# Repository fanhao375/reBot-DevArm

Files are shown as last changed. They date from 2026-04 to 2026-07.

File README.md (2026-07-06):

# 🦾 reBot-DevArm: Open Source Robotic Arm for All Developers

<p align="center">
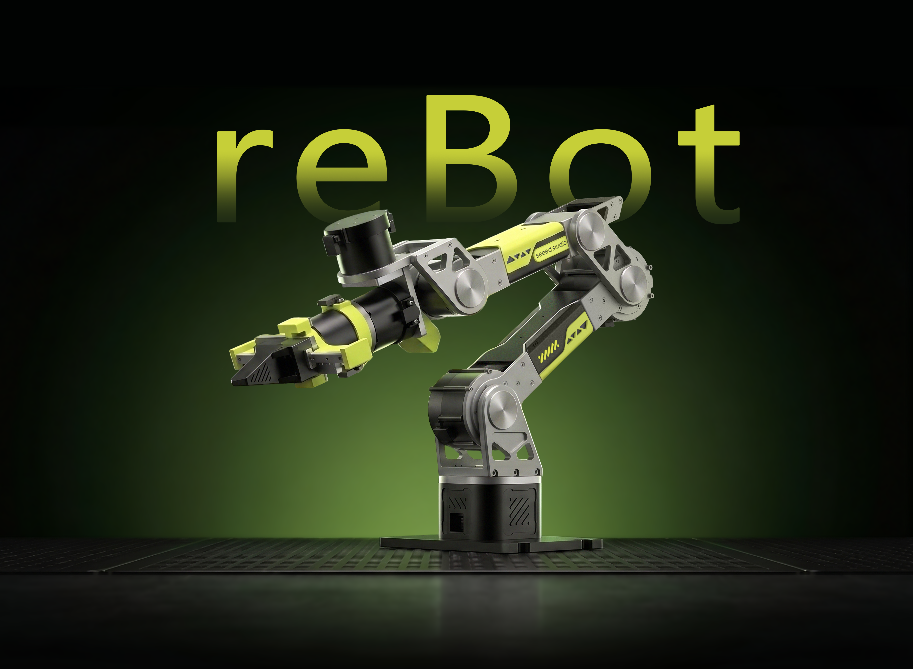
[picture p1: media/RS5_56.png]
reBot-DevArm Banner
  
</p>

<p align="center">
    <a href="https://certification.oshwa.org/cn000024.html">
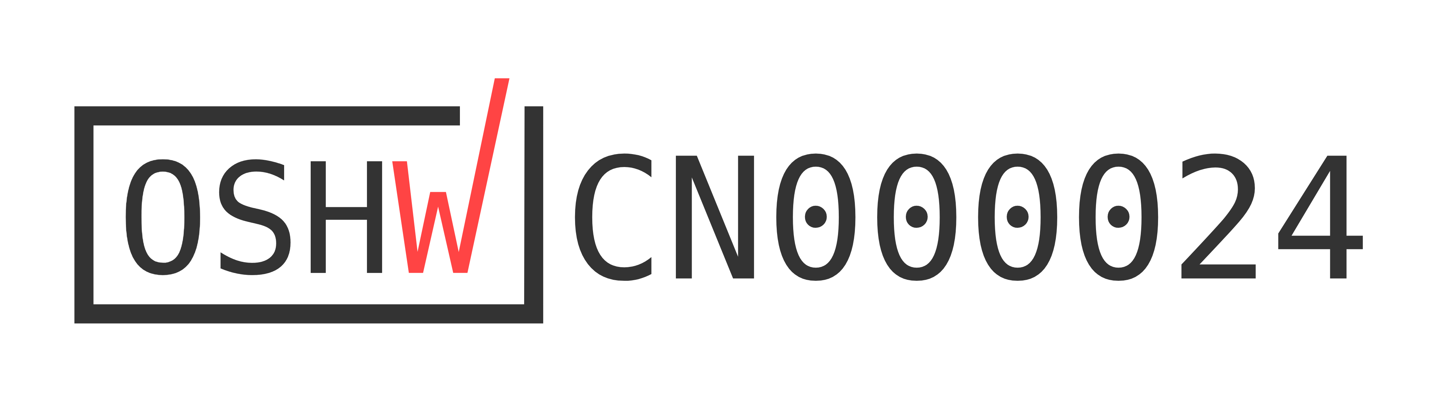
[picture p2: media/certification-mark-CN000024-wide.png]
  
</a>
</p>

<p align="center">
    <a href="./LICENSE">
    
    </a>
    
    </a>
    
    
    
    
</p>

<p align="center">
  <strong>🚀 100% Open Source · Embodied AI · Full Hardware + Software Stack</strong>
</p>

<p align="center">
  <strong>📦 Build your own robotic arm · 🧠 Learn robotics · 🏭 Deploy real applications</strong>
</p>

<table align="center">
  <tr>
    <td>
      <a href="https://www.youtube.com/watch?v=ONbpv3seiG8">
        
      </a>
    </td>
    <td>
      <a href="https://www.youtube.com/watch?v=ONbpv3seiG8">
        About The reBot Arm
      </a>
    </td>
  </tr>
</table>

<p align="center">
  <strong>
    <a href="./README_zh.md">简体中文</a> &nbsp;|&nbsp;
    <a href="./README.md">English</a> &nbsp;|&nbsp;
    <a href="./README_JP.md">日本語</a>&nbsp;|&nbsp;
    <a href="./README_Fr.md">français</a>&nbsp;|&nbsp;
    <a href="./README_es.md">Español</a>
  </strong>
</p>

<p align="center">
<a href="https://discord.gg/AbGuqJhDpQ">
    </a>
<a href="https://wiki.seeedstudio.com/robotics_page/">  
    </a>
</p>

## 📖 Introduction

**reBot-DevArm (reBot Arm B601 DM and reBot Arm B601 RS)** is a robotic arm project dedicated to lowering the barrier to learning Embodied AI. We focus on **"True Open Source"** — not just the code, we unreservedly open source everything:
- 🦾 **Two versions of the robotic arm**：We will provide all open-source files for two versions of the robotic arm with the same appearance: **Robostride** and **Damiao**.
- 🛠️ **Hardware Blueprints**: Source files for sheet metal parts and 3D printed parts.
- 🔩 **BOM List**: Detailed down to the specifications and purchase links for every single screw.
- 💻 **Software & Algorithms**: Python SDK, ROS1/2, Isaac Sim, LeRobot, etc.

## Get Your Own reBot Arm

- We offer five kit options  at  [Seeedstudio.com](https://www.seeedstudio.com/reBot-Arm-B601-DM-Bundle.html) :
  - **Arm Body Motor Kit**: Includes only motors and wiring harnesses for the robotic arm.
  - **Arm Body Structural Kit**: Includes only mechanical structural components.
  - **Gripper Complete Kit**: Includes motors, wiring harnesses and structural components for the gripper.
  - **Full Kit**: Includes the complete set of the robotic arm body and gripper.
  - **Pre‑assembled Robotic Arm**: Fully assembled finished robotic arm.

- The Seeedstudio kit does not include a power adapter and C-clamps as standard accessories. This arrangement takes into account that users may power the unit via batteries or mount it with a custom DIY base. You may purchase a [power supply separately](https://www.seeedstudio.com/AC-DC-Power-Adapter-IEC-60320-C14-XT30-Female-24V-4-5A-1200mm-L190-W92-5-H36mm-p-6764.html) and [Power Cord](https://www.seeedstudio.com/reServer-AC-US-p-5052.html), or refer to the Mean Well power solution shown at the bottom of our [BOM](./hardware/reBot_B601_DM/readme.md/#about-power-supply).

- You can also purchase the [Leader Arm](https://www.seeedstudio.com/Star-Arm-102-p-6765.html?qid=P2U7IG_yskyak5m_1776415593315) and [12V 10A Power Supply](https://www.seeedstudio.com/FY1209900-12V-10A-Power-Adapter-12V-10A-p-6496.html) You may also use the 12VDC power adapter of SO-ARM101 to supply power to the Leader.

-------------------
- For reBot Arm RS Version, We offer five kit options  at  [Seeedstudio.com](https://www.seeedstudio.com/reBot-Arm-B601-RS-Assembled-Kit-with-Gripper-p-6865.html) :
  - **Full Kit**: Includes the unassembled complete set of the robotic arm body and gripper.
  - **Pre‑assembled Robotic Arm**: Fully assembled finished robotic arm.

- We highly recommend using the [Meanwell 48V 12.5A](https://www.amazon.com/sspa/click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) power supply for the RS model. If you need stronger power to unlock its full performance, you may opt for a 48V 25A power adapter.
------------------

## 🗺️ Roadmap & Status

We are committed to continuously maintaining and adapting to mainstream robot development ecosystems. Below is our current adaptation progress and planned release schedule:

### reBot Arm B601 DM
| Supported Ecosystem | Status | Description / Estimated Release Date | Related Documentation |
| :--- | :---: | :--- | :--- |
| **Basic Motor Usage** | ✅ Completed | Basic motion control and API encapsulation | [Damiao Technology](https://wiki.seeedstudio.com/cn/damiao_series/) |
| **Open-Sourcing of the New STEP 3D Structural Parts and BOM** | ✅ Completed | STEP files for all parts in the new version, parts BOM, and reference prices for all machined components | [reBot Arm B601-DM BOM](./hardware/reBot_B601_DM/readme.md) |
| **Reference for Real Machine Performance Testing** | ✅ Completed | Performance Reference of Robotic Arm under Normal and Extreme Operating Conditions |[Performance Testing](./hardware/reBot_B601_DM/performance_testing/Performance_Testing.md) |
| **Assembly Video** | ✅ Completed | Ultra-detailed assembly steps and video | [Getting Started with reBot Arm B601-DM](https://wiki.seeedstudio.com/rebot_b601_dm_getting_started/) |
| **Python SDK** | ✅Continuously optimized, PRs welcome | One-stop integration of motor read/write and control for Robstride, Damiao, Mota, Gaoqing, Hexfellow and other motors. | [Getting Started with Motorbridge](https://motorbridge.seeedstudio.com) and [Web UI](https://rebot-devarm.w0x7ce.eu/)|
| **ROS2 Integration** | ✅ Completed | ROS2 integrated reBot Arm controller with support for kinematics, trajectory planning, and gravity compensation | [reBot Arm B601-DM ROS2 Integration Guide](https://wiki.seeedstudio.com/rebot_arm_b601_dm_ros2_integration/) |
| **Pinocchio Integration** |  ✅ Completed  | Adaptation to the Pinocchio framework, enabling forward/inverse kinematics and gravity compensation for the robotic arm | [Getting Started with Pinocchio for reBot Arm B601-DM](https://wiki.seeedstudio.com/rebot_arm_b601_dm_pinocchio_meshcat/) and [Github repo](https://github.com/vectorBH6/reBotArm_control_py) |
| **Isaac Sim Simulation** | 🚧 In Progress  | Import USD models and enable simulated teleoperation | [delay for add additional courses: 2026.06.20] |
| **LeRobot Integration** | ✅ Completed  | Adaptation to the Hugging Face LeRobot training framework | [Getting Started with LeRobot-based reBot Arm](https://wiki.seeedstudio.com/rebot_arm_b601_dm_lerobot/) |
| **Depth Camera Integration** | ✅ Completed  | Visual Grasping Demonstration Based on YOLO and Depth Camera | [Getting Started with Visual Grasping Demo](https://wiki.seeedstudio.com/rebot_arm_b601_dm_grasping_demo/) |
| **reSpeaker Voice Integration** | ✅ Completed  | Add reSpeaker Flex 4-mic array to build a voice-driven intelligent robot arm control system with spatial awareness | [reBot Arm B601-DM Voice Control](https://wiki.seeedstudio.com/control_rebot_arm_using_voice_with_respeaker_flex/) |
| **Gradual Updates of the Latest Algorithms** | ⏳ Planned | Mainstream algorithms will be updated progressively | Ongoing |
| **Launch of a Series of Completely Free Courses** | ⏳ Planned | Mainstream algorithms will be updated progressively | Ongoing |

#### Contributions from Developers 
| Supported Ecosystem | Authors | Description / Estimated Release Date | Related Documentation or Repository |
| :--- | :---: | :--- | :--- |
| **ROS2 (Humble), third_party integration, URDF / rebotarm_bringup** | [@danieldoradotalaveron-rb](https://github.com/danieldoradotalaveron-rb) | 1. **Passive diagnostics monitor** (`rebotarm_monitor_ros2`): `/diagnostics` overlay for `rqt_robot_monitor`, serial/CAN-aware aggregator;<br>2. **Safe park & shutdown**: Capture rest pose on connect, slow return on shutdown or `/rebotarm/park` to prevent sudden drop;<br>3. **Gravity compensation (smooth stop)**: MIT ramp-out when exiting gravity compensation to eliminate clack, jerk and instability during pos/vel handoff;<br>4. **Gamepad teleop with IK/FK and safety measures**: Gamepad control for end-effector via IK, live robot state visualization in RViz (simulation-only test);<br>5. **D405 eye-in-hand TF**: Xacro setup under `end_link` in `rebotarm_bringup` for RViz visualization & TF only (no driver/depth/intrinsics). Mount pose adjustable via launch file, bracket calibration not completed. Teleop FK/IK uses arm-only `fixend_core` URDF, full xacro for RSP/RViz. | [rebotarm_monitor_ros2](https://github.com/danieldoradotalaveron-rb/rebotarm_monitor_ros2)、[reBotArmController_ROS2](https://github.com/danieldoradotalaveron-rb/reBotArmController_ROS2) |

### reBot Arm B601 RS

| Supported Ecosystem | Status | Description / Estimated Release Date | Related Documentation |
| :--- | :---: | :--- | :--- |
| **Basic Motor Usage** | ✅ Completed | Basic motion control and API encapsulation | [Robstride](https://wiki.seeedstudio.com/cn/robstride_control/) |
| **Open-Sourcing of the New STEP 3D Structural Parts and BOM** | 🚧 In Progress | STEP files for all parts in the new version, parts BOM, and reference prices for all machined components | Expected [2026.06] |
|**Getting Started**| ✅ Completed | Quick start of B601-RS| [Getting Started with reBot Arm B601-RS](https://wiki.seeedstudio.com/rebot_b601_rs_getting_started/) |
| **Assembly Video** | 🚧 In Progress | Ultra-detailed assembly steps and video | [Expected 2026.06] |
| **ROS2 (Humble)** | ✅ Completed | ROS2 integrated reBot Arm controller with support for kinematics, trajectory planning, gravity compensation and MoveIt2 | [reBot Arm B601-DM ROS2 Integration Guide](https://wiki.seeedstudio.com/rebot_arm_b601_rs_ros2_integration/) |
| **LeRobot Integration** |✅ Completed| Adaptation to the Hugging Face LeRobot training framework | [Getting Started with LeRobot-based reBot Arm](https://wiki.seeedstudio.com/rebot_arm_b601_rs_lerobot/) |
| **Pinocchio Integration** | ✅ Completed | Adaptation to the Pinocchio framework, enabling forward/inverse kinematics and gravity compensation for the robotic arm | [Getting Started with Pinocchio for reBot Arm B601-DM](https://wiki.seeedstudio.com/rebot_arm_b601_rs_pinocchio_meshcat/) and [Github repo](https://github.com/vectorBH6/reBotArm_control_py) |
| **Depth Camera Integration** | ✅ Completed  | Visual Grasping Demonstration Based on YOLO and Depth Camera | [Getting Started with Visual Grasping Demo](https://wiki.seeedstudio.com/rebot_arm_b601_dm_grasping_demo/) |
| **Isaac Sim Simulation** | ⏳ Planned | Import USD models and enable simulated teleoperation | [Github Repo](https://github.com/Seeed-Projects/reBot-Isaacsim) |
| **Gradual Updates of the Latest Algorithms** | ⏳ Planned | Mainstream algorithms will be updated progressively | On going |
| **Launch of a Series of Completely Free Courses** | ⏳ Planned | Mainstream algorithms will be updated progressively | Ongoing |

---

## ⚙️ Hardware Specifications

reBot-DevArm is designed for desktop Embodied AI applications, balancing payload capacity with flexibility.

| Parameter | reBot Arm B601-DM | reBot Arm B601-RS|
| :--- | :--- | :--- |
| **Payload** | 1.5kg | **2.5kg** |
| **Recommended Workspace** | 70% arm reach workspace | 70% arm reach workspace |
| **Max Reach** | 767 mm | **754 mm** |
| **Weight** | **Approx. 4.5 kg** | Approx. 6.7 kg |
| **Repeatability** | < 0.2 mm | < 0.2 mm |
| **Degrees of Freedom (DOF)** | 6 DOF + 1 Gripper | 6 DOF + 1 Gripper |
| **Supported Platforms/Ecosystems** | ROS1, ROS2, LeRobot, Pinocchio, Isaac Sim, Python SDK | ROS1, ROS2, LeRobot, Pinocchio, Isaac Sim, Python SDK |
| **Supply Voltage** | DC 24V | DC 48V |

## Feedback from the community
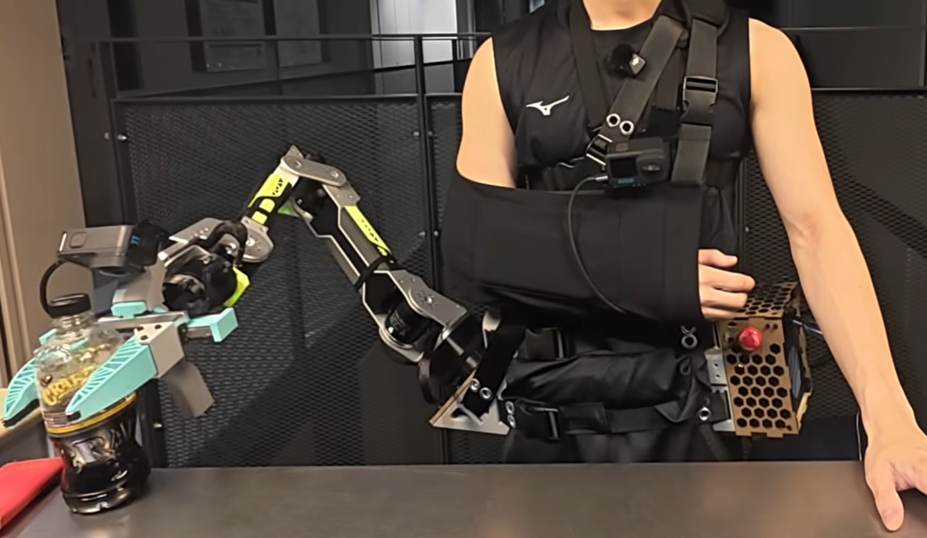
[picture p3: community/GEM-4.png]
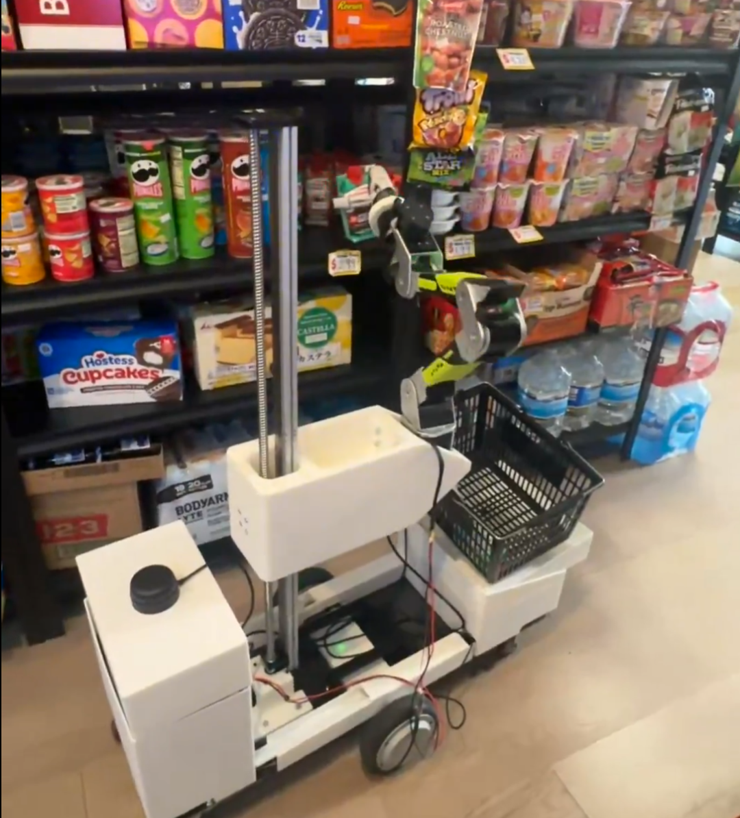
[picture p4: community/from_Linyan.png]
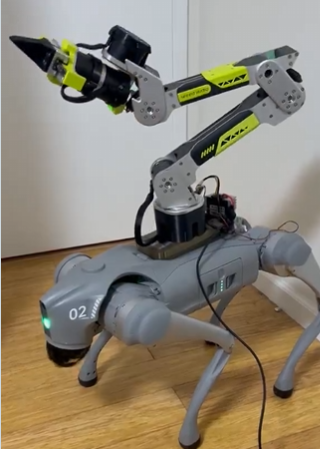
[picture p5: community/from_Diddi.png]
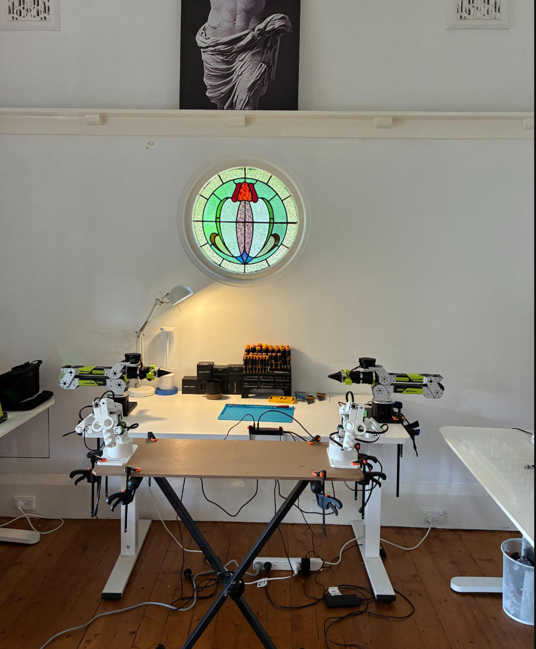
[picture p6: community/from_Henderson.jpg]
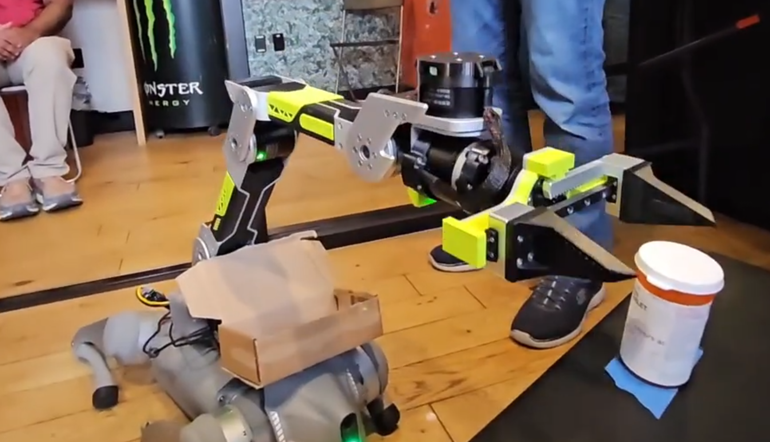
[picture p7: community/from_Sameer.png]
|  |  |  |  | |
| --- | --- | --- | --- |  --- |
| [From GEM-4: Gemma Embodied 4 Physical Assistance](https://www.kaggle.com/competitions/gemma-4-good-hackathon/writeups/new-writeup-1778618527713) | [From Linyan Fu](https://x.com/Linyan_Fu/status/2056383947341525180)  and [Apheth D Almeida](https://x.com/Apheth_DAlmeida/status/2053503164507476096)| [From Dhruv Diddi](https://x.com/DhruvDiddi/status/2046605015008383284)  | [From Ed Henderson](https://x.com/ed0henderson/status/2055076839002095743)  | From Sameer | 
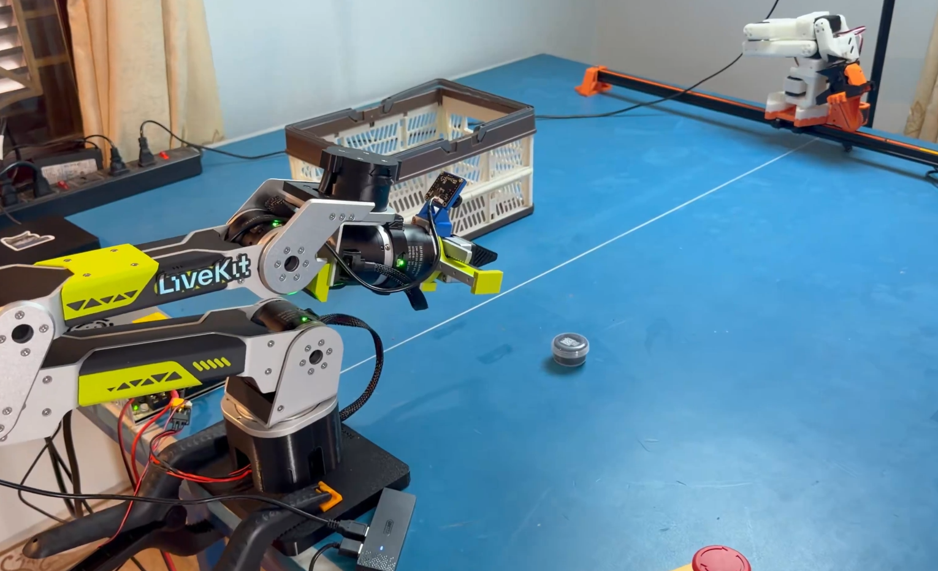
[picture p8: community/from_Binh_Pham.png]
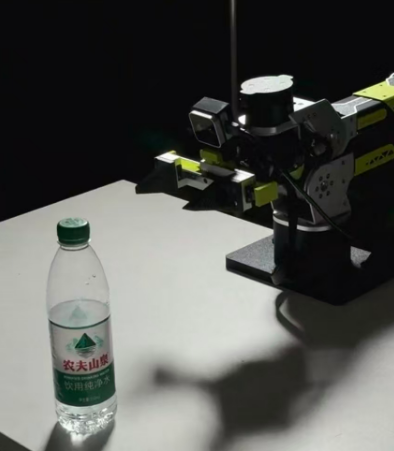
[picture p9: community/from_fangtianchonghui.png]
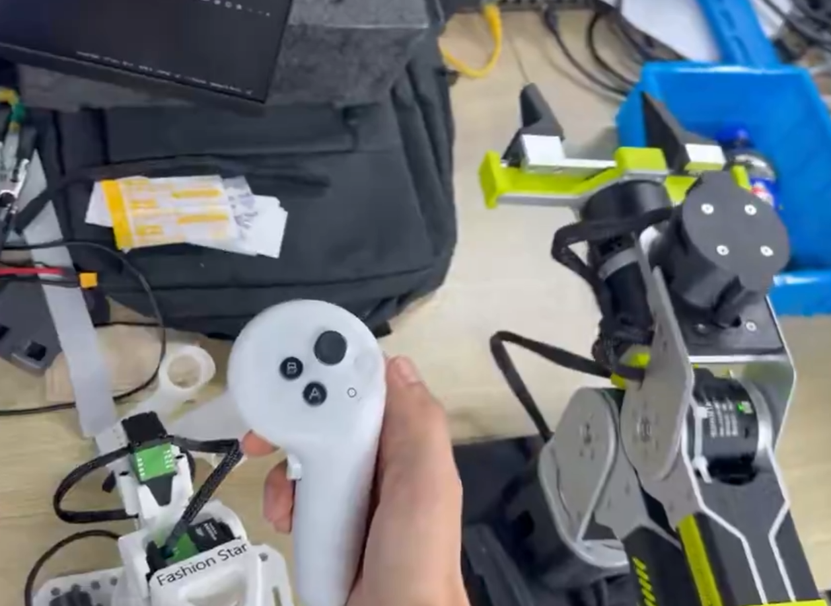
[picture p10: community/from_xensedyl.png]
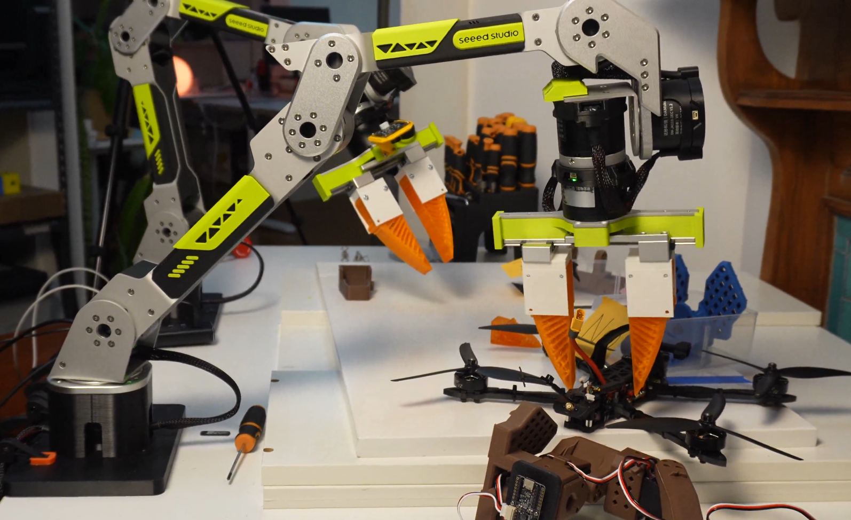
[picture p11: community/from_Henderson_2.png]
|  |  |  |  | |
| [From Binh_Pham](https://x.com/pham_blnh/status/2061994096374505710) | [From FangTianChongHui](https://www.instagram.com/reel/DY7Ny8OPjVu/?utm_source=ig_web_copy_link&igsh=NTc4MTIwNjQ2YQ==)| [Xense YaoLin Dong](https://x.com/dong1505lin)  | [From Ed Henderson](https://x.com/ed0henderson/status/2055076839002095743)  | | 

## 🧹Optional Hardware
###  Wirst Camera Mount
| 32×32 UVC  | Intel D435i | Intel D405 & Gemini 305 | Gemini 2|
| --- | --- | --- | --- |
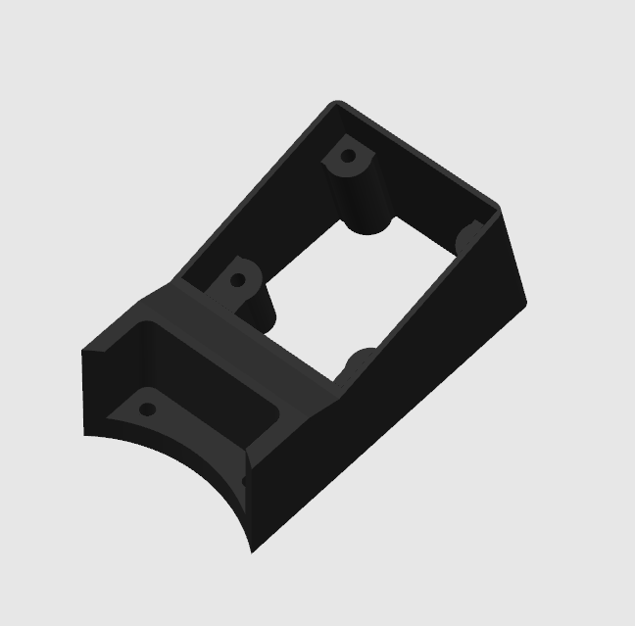
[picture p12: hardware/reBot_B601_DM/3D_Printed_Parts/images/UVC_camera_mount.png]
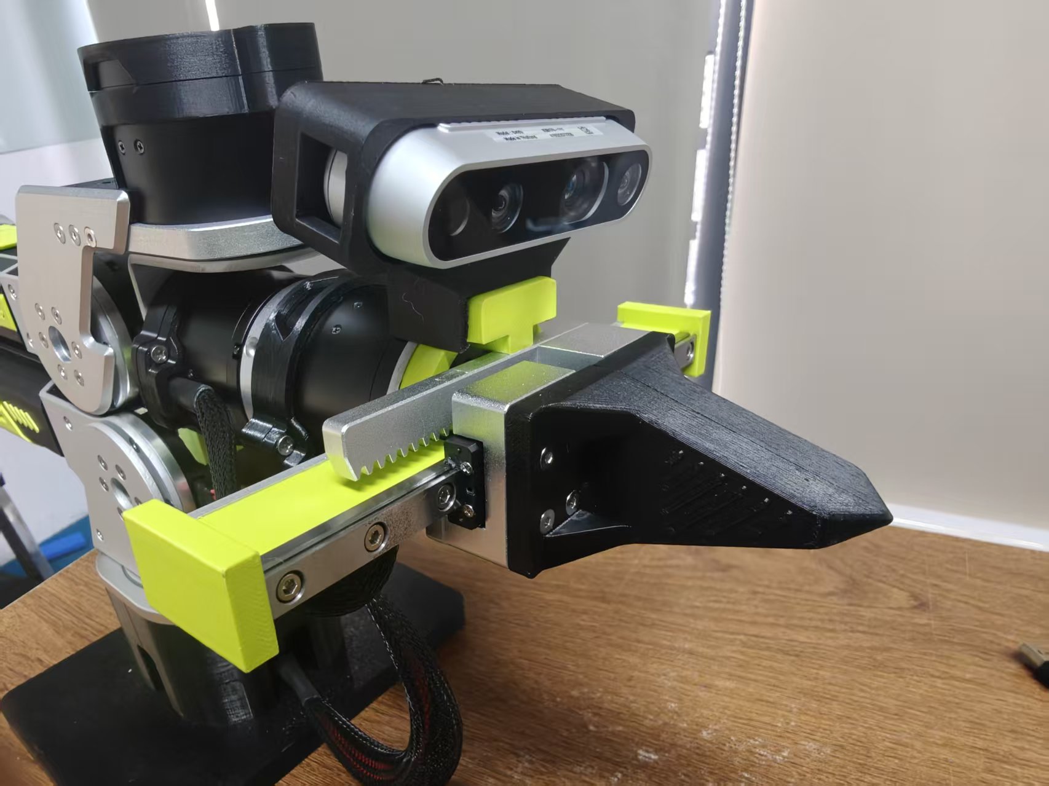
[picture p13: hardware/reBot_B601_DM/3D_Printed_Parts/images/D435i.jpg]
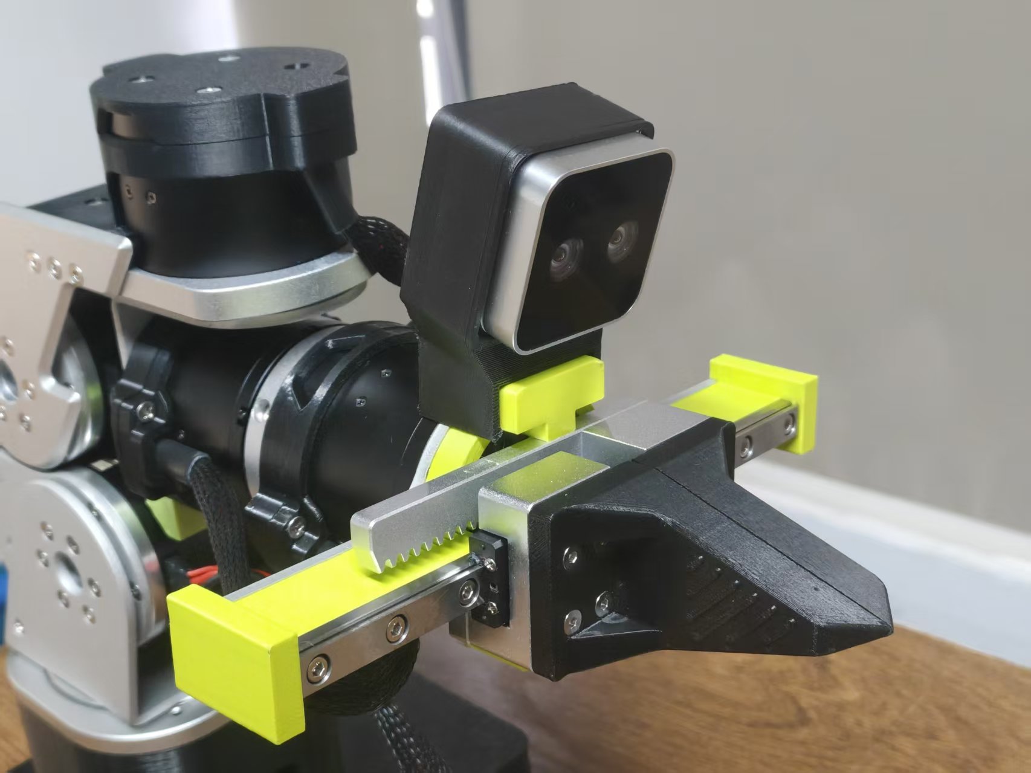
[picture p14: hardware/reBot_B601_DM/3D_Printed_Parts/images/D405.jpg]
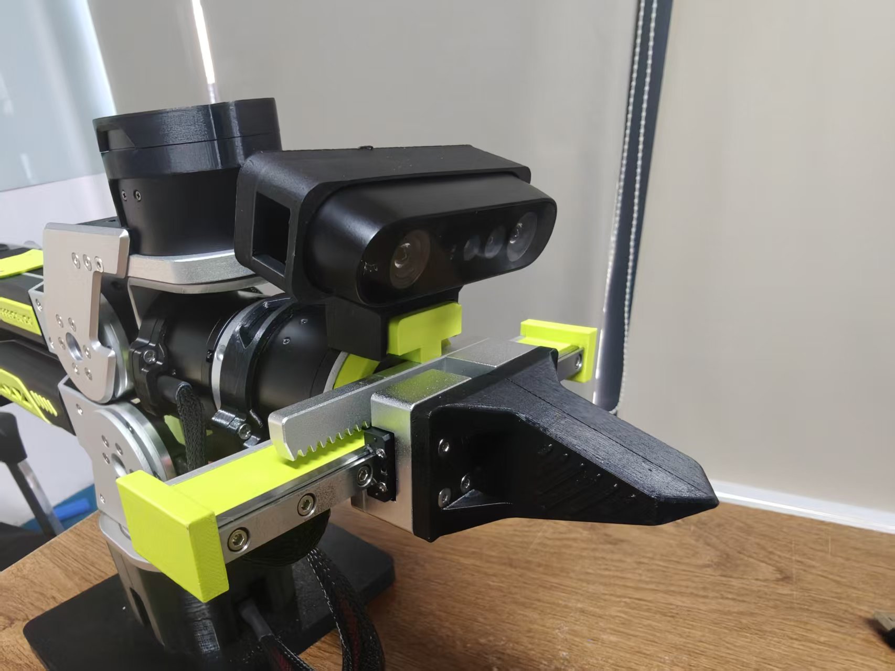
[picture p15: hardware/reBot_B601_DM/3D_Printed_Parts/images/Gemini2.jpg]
|  |  |   |  | 
| [STEP](/hardware/reBot_B601_DM/3D_Printed_Parts/UVC32_mount.step) | [STEP](/hardware/reBot_B601_DM/3D_Printed_Parts/D435_Gemini2_Mount.step) | [STEP](/hardware/reBot_B601_DM/3D_Printed_Parts/D405_305_Mount.step) |[STEP](/hardware/reBot_B601_DM/3D_Printed_Parts/D435_Gemini2_Mount.step) |

###  Compatible with Leader Arm
| Star Arm 102-LD  |  Open to compatibility integration  | 
| --- | --- |
|    |Comming soon| 
|  [Github repo](https://github.com/servodevelop/Star-Arm-102) |Comming soon |

### DIY Finger
| Soft Finger  |  Open to compatibility integration  | 
| --- | --- |
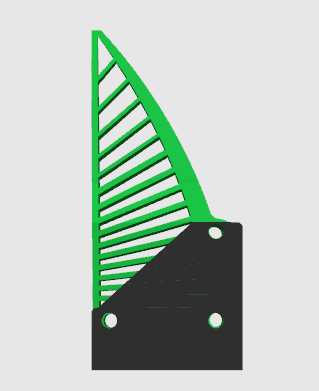
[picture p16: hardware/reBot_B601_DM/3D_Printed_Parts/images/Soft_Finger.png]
|    |Comming soon| 
| [Finger Mount(ABS/PLA)](/hardware/reBot_B601_DM/3D_Printed_Parts/Soft_Gripper_Mount.step) and [Finger (TPU 95+)](/hardware/reBot_B601_DM/3D_Printed_Parts/Soft_Gripper_Finger.step)  |Coming soon |

### Recommended Optional Hardware
<table>
  <thead>
    <tr>
      <th>Category</th>
      <th>Type</th>
      <th>Preview</th>
      <th>Product</th>
      <th>Link</th>
    </tr>
  </thead>
  <tbody>
    <tr>
      <td rowspan="8" align="center"><strong>Camera</strong></td>
      <td rowspan="6" align="center">Depth Camera</td>
      <td align="center">Orbbec Gemini 2 3D Camera</td>
      <td><strong>Orbbec Gemini 2 3D Camera</strong></td>
      <td><a href="https://www.seeedstudio.com/Orbbec-Gemini-2-3D-Camera-p-6464.html">Seeed Studio</a></td>
    </tr>
    <tr>
      <td align="center">Orbbec Gemini 336 Depth Camera</td>
      <td><strong>Orbbec Gemini 336 Depth Camera</strong></td>
      <td><a href="https://www.seeedstudio.com/Orbbec-Gemini-336-3D-Camera-3D-p-6662.html">Seeed Studio</a></td>
    </tr>
    <tr>
      <td align="center">Orbbec Gemini 335LG 3D Camera</td>
      <td><strong>Orbbec Gemini 335LG 3D Camera</strong></td>
      <td><a href="https://www.seeedstudio.com/Orbbec-Gemini-335LG-3D-Camera-p-6541.html">Seeed Studio</a></td>
    </tr>
    <tr>
      <td align="center">SLAMTEC Aurora S, Integrated Spatial Perception Module</td>
      <td><strong>SLAMTEC Aurora S</strong><br></td>
      <td><a href="https://www.seeedstudio.com/SLAMTEC-Aurora-S-AI-Integrated-Spatial-Perception-System-p-6669.html">Seeed Studio</a></td>
    </tr>
    <tr>
      <td align="center">Intel RealSense Depth Camera D435i</td>
      <td><strong>Intel RealSense Depth Camera D435i</strong></td>
      <td><a href="https://www.seeedstudio.com/Intel-RealSense-Depth-Camera-D435i-p-4423.html">Seeed Studio</a></td>
    </tr>
    <tr>
      <td align="center">RealSense Depth Camera D405</td>
      <td><strong>RealSense Depth Camera D405</strong></td>
      <td><a href="https://www.seeedstudio.com/RealSense-D405-3D-Camera-p-6758.html">Seeed Studio</a></td>
    </tr>
    <tr>
      <td rowspan="2" align="center">Monocular Camera</td>
      <td align="center">Sensing SG3S-ISX031C-GMSL2F 3MP GMSL2 Camera</td>
      <td><strong>Sensing SG3S-ISX031C-GMSL2F 3MP GMSL2 Camera</strong></td>
      <td><a href="https://www.seeedstudio.com/SG3S-ISX031C-GMSL2F-p-6245.html">Seeed Studio</a></td>
    </tr>
    <tr>
      <td align="center">ET-S231 Megapixel 120 Degree Wide-Angle 1080P USB Camera Module</td>
      <td><strong>ET-S231 Megapixel 120 Degree Wide-Angle 1080P USB Camera Module</strong></td>
      <td><a href="https://www.seeedstudio.com/ET-S231-120-USB-Camera-p-6683.html">Seeed Studio</a></td>
    </tr>
    <tr>
      <td rowspan="2" align="center"><strong>Microphone</strong></td>
      <td rowspan="2" align="center">Mic Array</td>
      <td align="center">reSpeaker Flex XVF3800 Circular-4 with XIAO ESP32S3</td>
      <td><strong>reSpeaker Flex XVF3800 Circular-4 with XIAO ESP32S3</strong><br><sub>AI Mic Array for Robotics and Embodied AI</sub></td>
      <td><a href="https://www.seeedstudio.com/reSpeaker-Flex-XVF3800-Circular-4-with-XIAO-ESP32S3-p-6739.html">Seeed Studio</a></td>
    </tr>
    <tr>
      <td align="center">reSpeaker XMOS XVF3800</td>
      <td><strong>reSpeaker XMOS XVF3800</strong><br><sub>AI-powered 4-Mic Array for Clear Voice Even in Noise</sub></td>
      <td><a href="https://www.seeedstudio.com/ReSpeaker-XVF3800-USB-Mic-Array-p-6488.html">Seeed Studio</a></td>
    </tr>
    <tr>
      <td rowspan="2" align="center"><strong>Controller</strong></td>
      <td rowspan="2" align="center">Edge Controller</td>
      <td align="center">reComputer J3011-Orin Nano 8GB</td>
      <td><strong>reComputer J3011-Orin Nano 8GB</strong></td>
      <td><a href="https://www.seeedstudio.com/reComputer-J3011-p-5590.html">Seeed Studio</a></td>
    </tr>
    <tr>
      <td align="center">NVIDIA Jetson AGX Thor Developer Kit</td>
      <td><strong>NVIDIA Jetson AGX Thor Developer Kit</strong></td>
      <td><a href="https://www.seeedstudio.com/NVIDIA-Jetson-AGX-Thor-Developer-Kit-p-9965.html">Seeed Studio</a></td>
    </tr>
  </tbody>
</table>

---

### 🎓 Full-Stack Robotics Ecosystem
reBot-DevArm is not just a robotic arm, but a robotics learning community. We share the following general tutorials for free:

#### 🖥️ Edge Computing & Master Control
*    —— **AI Inference & Compute Core**
*    —— **General Linux Development Environment**
*    —— **Low-power Wireless Control Node**

#### 📡 Sensors & Peripherals
*   **🚗 Motors & Servos**: [Damiao / Gogo / Robstride / Mita / Feite / Fashion Star](https://wiki.seeedstudio.com/robotics_page/)
*   **👁️ Visual Perception**: [Depth Cameras / LiDAR / Vision Algorithms](https://wiki.seeedstudio.com/robotics_page/)
*   **👂 Voice Interaction**: [reSpeaker Mic Arrays/Voice Control/Spatial Awareness(DoA)](https://wiki.seeedstudio.com/control_rebot_arm_using_voice_with_respeaker_flex/)
*   **🧭 Motion & Attitude**: [IMU (6-axis/9-axis) / Gyroscopes / Magnetometers](https://wiki.seeedstudio.com/Sensor/IMU/)
*   **🤖 Comprehensive Kits**: [More Robotics Sensors & Driver Examples](https://wiki.seeedstudio.com/robotics_page/)

> 👉 **[Click to Enter Wiki Knowledge Base](https://wiki.seeedstudio.com/)** (All tutorials are free to view)

---

## 🙌 References & Acknowledgments
The path of open source is never lonely. The birth of the reBot-DevArm project would not be possible without the full support of Seeed Studio, the global open source community, and excellent hardware partners. We pay our highest respects to the following projects and teams:

### 🌍 Ecosystem & Software Support
*   **[Seeed Studio](https://www.seeedstudio.com/)** - Providing comprehensive hardware supply chain and technical support.
*   **[Hugging Face LeRobot](https://github.com/huggingface/lerobot)** - An excellent end-to-end robot learning framework.
*   **[NVIDIA Isaac Sim](https://developer.nvidia.com/isaac/sim)** - A powerful robot simulation and synthetic data platform.

### ⚙️ Core Hardware Partners
Thanks to the following manufacturers for providing high-performance motor and actuator solutions:
*   **[Damiao Technology](https://www.damiaokeji.com/)**
*   **[Robstride](https://robstride.com/)**
*   **[Fashion Star](https://fashionstar.com.hk/wiki/)**

### 💡 Inspiration
This project is deeply inspired by the following excellent open source projects:
*   **[SO-ARM100](https://github.com/TheRobotStudio/SO-ARM100/tree/main)**
*   **[Mobile ALOHA](https://github.com/tonyzhaozh/aloha)**
*   **[Dummy-Robot (Zhihui Jun)](https://github.com/peng-zhihui/Dummy-Robot)**
*   **[OpenArm](https://openarm.dev/)**
*   **[I2RT](https://i2rt.com/)**
*   **[TRLC-DK1](https://github.com/robot-learning-co/trlc-dk1)**

### 🎃 Prototype Contributors
- **SeeedStudio AI Robotics Team's**: Yaohui Zhu (yaohui.zhu@seeed.cc)
- **SeeedStudio STU**: Wentao Dong
- **SeeedStudio STU**: Weiwei Xu
- **SeeedStudio Purchasing Department**: Fengqun Peng

### 👥 Contributors

## Our Top Contributors 
<p align="center"><a href="https://github.com/Seeed-Projects/reBot-DevArm/graphs/contributors">
  
</a></p>

*Coming soon... Welcome to submit PRs to become a contributor!*

## Star History

Star History Chart (https://www.star-history.com/#Seeed-Projects/reBot-DevArm&type=date&legend=top-left)

# reBot-DevArm Project License

- **Hardware Design** © 2026 Seeed Studio Co., Ltd. (SeeedStudio), open-sourced under [CERN-OHL-W-2.0](https://ohwr.org/cern_ohl_w_v2.txt)
- **Firmware Code** © 2026 Seeed Studio Co., Ltd. (SeeedStudio), open-sourced under [Apache-2.0](https://www.apache.org/licenses/LICENSE-2.0)

## Rights and Restrictions

Dear developers and industry experts, the reBot Arm robotic arm project has always adhered to the core philosophy of **Agility, Openness, Responsibility, and Symbiosis** to serve the developer community. Our vision is to enable every enthusiast to systematically master the hardware architecture and software principles of robotic arms, and to gain an immersive experience with cutting-edge embodied intelligence algorithms through the reBot project.

For the first five months since launch, the project has been using the **CC BY-SA NC (Non-Commercial) open source license**. The original intention was to allow all developers and contributors to focus on iterating and improving the product during its initial, less mature phase, free from commercial concerns, and to fully dedicate themselves to project co-construction and optimization.

After months of in-depth product polishing and technical refinement by Seeed Studio, **effective May 11, 2026**, the reBot Arm project has officially transitioned from the CC BY-SA NC license to the **CERN-OHL-W 2.0 open source license**.

From this point forward, the project achieves **100% full-stack open source (both hardware and software), granting full commercial compliance and usage rights for all scenarios**.

We look forward to your continued participation with an inclusive and collaborative spirit, to sustain, maintain, and deepen the reBot Arm open source community, to share the fruits of open source, and together build an ecosystem for embodied intelligence.

This project uses different open source licenses for Hardware and Software. Please confirm the license terms applicable to the part you are using.

| Item / License | reBot Hardware: CERN-OHL-W-2.0 | reBot Software SDK: Apache-2.0 |
| --- | --- | --- |
| **✅ Commercial Use Allowed** | ✅ Allowed | ✅ Allowed |
| **✅ Modification Allowed** | ✅ Allowed | ✅ Allowed |
| **✅ Redistribution Allowed** | ✅ Allowed | ✅ Allowed |
| **✅ Closed-source Integration/Redistribution** | ❌ Conditional (see [CERN-OHL-W-2.0](https://ohwr.org/cern_ohl_w_v2.txt) for details) | ✅ Allowed (no need to disclose modified code) |
| **⚠️ Copyright Retention Required** | ✅ Required | ✅ Required |
| **⚠️ License Text Retention Required**  | ✅ Required | ✅ Required |
| **⚠️ Modification Notice Required** | ✅ Required (with date and description) | ✅ Required (with modification description) |
| **⚠️ Patent Grant** | ✅ Explicit patent grant (see [CERN-OHL-W-2.0](https://ohwr.org/cern_ohl_w_v2.txt) for details) | ✅ Explicit patent grant |
| **⚠️ Source Provision upon Distribution** | ✅ **Must** provide hardware "Complete Source" | ❌ No mandatory source provision requirement |
| **⚠️ External/Closed Module Compatibility** | ✅ Allowed (Weakly Reciprocal feature) | ✅ Fully allowed |
| **🔗 Relationship with Other Components/Modules** | Independent interface modules (External Material) may retain original closed license | No restrictions, can link with code under any license |
| **📄 Official License Full Text** | [CERN-OHL-W-2.0](https://ohwr.org/cern_ohl_w_v2.txt) | [Apache-2.0](https://www.apache.org/licenses/LICENSE-2.0) |

## ☎ Contact Us
- **Open‑Source Progress & Technical Support**-Yaohui: yaohui.zhu@seeed.cc
- **Future Collaboration & Customization**-Elaine: elaine.wu@seeed.cc

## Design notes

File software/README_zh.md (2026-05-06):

# reBot-DevArm 软件资料总览

> 整理日期：2026.05.06
> 来源：reBot-DevArm 项目 2026年4-5月更新，新增 Python SDK、Pinocchio 适配和 ROS2 集成

---

## 这些东西从哪来的？

reBot-DevArm 主仓库（hardware/）从一开始就有硬件资料，但核心控制软件长期放在独立仓库里。
2026年4-5月更新后，路线图中的软件能力主要指向这些外部仓库：

| 仓库 | 来源 | 说明 |
|---|---|---|
| **MotorBridge** | https://github.com/motorbridge/motorbridge | Python SDK 完成后指向的通用电机控制栈 |
| **reBotArm_control_py** | https://github.com/vectorBH6/reBotArm_control_py | Pinocchio 完成后指向的运动学控制库 |
| **reBotArmController_ROS2** | https://github.com/EclipseaHime017/reBotArmController_ROS2 | ROS2 集成教程实际引用的 ROS2 工作区 |
| **wiki_docs** | https://wiki.seeedstudio.com/ | 官方 wiki 教程离线存档（10 个页面，OpenCLI 抓取） |

这些仓库本质上仍是独立项目；当前仓库通过 `git submodule` 方式固定它们的版本，方便学习、同步和复现。

说明：
- `MotorBridge` 当前 submodule 指向 `fanhao375/motorbridge`，上游源是 `motorbridge/motorbridge`
- `reBotArm_control_py` 的源码上游是 `vectorBH6/reBotArm_control_py`，但本项目当前 submodule 指向 `fanhao375/reBotArm_control_py` 的 `develop`，用于承接本地修复并保证远端可复现
- `reBotArmController_ROS2` 的当前可用上游是 `EclipseaHime017/reBotArmController_ROS2`；本项目 submodule 指向 `fanhao375/reBotArmController_ROS2` 的 `main`
- 2026-05-06 检查时，`Seeed-Projects/reBotArmController_ROS2` 对 Git 仍返回 404，暂不作为 upstream

---

## 目录结构

```
software/
├── docs/                        📚 文档中心（新增）
│   ├── README.md                文档导航（推荐学习路径）
│   ├── 00_新手入门/
│   │   ├── URDF_入门指南.md     什么是 URDF、Link、Joint
│   │   ├── MeshCat_可视化指南.md 浏览器 3D 预览工具
│   │   └── README.md
│   ├── 01_项目专用/
│   │   ├── reBot-DevArm_URDF详解.md  逐行解读本项目 URDF（448 行注释）
│   │   └── README.md
│   ├── 02_reBotArm_control_py/
│   │   ├── reBotArm_control_py_说明.md  Python 上层控制库架构
│   │   ├── reBotArm_control_py_architecture.drawio  架构图
│   │   ├── reBotArm_control_py_运行流程.drawio  数据流图
│   │   └── README.md
│   └── 03_MotorBridge/
│       ├── MotorBridge_说明.md  Rust 底层电机库架构
│       ├── MotorBridge_architecture.drawio  架构图
│       ├── MotorBridge_运行流程.drawio  发送/反馈流程图
│       └── README.md
│
├── MotorBridge/                 底层：通用电机控制栈
│   ├── motor_core/              Rust 核心（CAN 通信抽象）
│   ├── motor_vendors/
│   │   ├── damiao/              达妙电机驱动（reBot DM版用这个）
│   │   ├── robstride/           RobStride 电机驱动（reBot RS版用这个）
│   │   ├── myactuator/          MyActuator 电机
│   │   ├── hightorque/          HighTorque 电机
│   │   ├── hexfellow/           Hexfellow 电机（CANopen）
│   │   └── template/            新厂商接入模板
│   ├── motor_cli/               命令行工具（扫描/使能/控制电机）
│   ├── motor_abi/               C ABI 稳定接口
│   ├── bindings/
│   │   ├── python/              Python 绑定
│   │   └── cpp/                 C++ 绑定
│   ├── integrations/            ROS2 等集成
│   └── examples/                使用示例
│
├── reBotArm_control_py/         上层：运动学控制库（develop 分支）
│   ├── config/
│   │   └── robot.yaml           关节配置（电机ID/型号/PID参数）
│   ├── reBotArm_control_py/     核心库
│   │   ├── actuator/            电机执行器封装
│   │   ├── kinematics/          正/逆运动学（Pinocchio）
│   │   ├── dynamics/            动力学（重力补偿）
│   │   ├── trajectory/          轨迹规划（SE3测地线）
│   │   └── controllers/         控制器
│   ├── example/                 示例程序（按学习顺序排列）
│   │   ├── 0x01damiao_text.py       单电机调试
│   │   ├── 2_zero_and_read.py       零位校准 + 角度监控
│   │   ├── 3_mit_control.py         MIT 模式控制
│   │   ├── 4_pos_vel_control.py     位置速度模式控制
│   │   ├── 5_fk_test.py             正运动学测试
│   │   ├── 6_ik_test.py             逆运动学测试
│   │   ├── 7_arm_ik_control.py      IK 实时控制真机
│   │   ├── 8_arm_traj_control.py    轨迹规划控制
│   │   ├── 9_gravity_compensation.py    重力补偿（自由拖动）
│   │   └── 10_gravity_compensation_lock.py  重力补偿+锁定
│   ├── urdf/                    URDF 模型
│   │   └── reBot-DevArm_fixend_description/
│   │       ├── urdf/            URDF 描述文件
│   │       ├── meshes/          3D 网格（base_link ~ link6 + end_link）
│   │       ├── launch/          ROS launch 文件
│   │       └── config/          关节名称配置
│   └── pyproject.toml           Python 项目配置
│
├── reBotArmController_ROS2/     ROS2：reBot B601 控制工作区（main 分支）
│   ├── src/rebotarm_bringup/    启动、配置、URDF/mesh、RViz
│   ├── src/rebotarm_msgs/       ROS2 msg/srv/action 定义
│   ├── src/rebotarmcontroller/  ROS2 控制节点、service、action、示例
│   ├── README.md                英文说明
│   └── README_zh.md             中文说明
│
├── wiki_docs/                   官方 wiki 教程离线存档（OpenCLI 抓取）
│   ├── Getting_Started_with_Pinocchio_.../  Pinocchio + MeshCat 入门
│   ├── 达妙系列电机/                        达妙 43 系列电机完整教程
│   ├── RobStride_电机控制完整指南/          RobStride 电机多语言控制
│   ├── DM_Gripper_.../                      达妙夹爪组装指南
│   ├── SoArm_in_Lerobot/                   SO100 机械臂 LeRobot 教程
│   ├── Starai_Arm_in_ROS2_MoveIt/          StarAI 机械臂 MoveIt2 教程
│   ├── Install_the_ROS2_Humble/            ROS2 Humble 安装教程
│   └── Robotics/                            Seeed Studio 机器人资源总索引
│
└── README_zh.md                 本文件
```

---

## 软件栈关系

```
ROS2 应用 / rqt / ros2 topic / action client
      │
      ▼
┌─────────────────────────────────────┐
│  reBotArmController_ROS2             │
│  ROS2 topic / service / action 封装   │
└──────────────┬──────────────────────┘
               │ 调用 Python 控制库
               ▼
┌─────────────────────────────────────┐
│  reBotArm_control_py                 │
│  IK / 轨迹规划 / 重力补偿             │
└──────────────┬──────────────────────┘
               │ 调用电机 SDK
               ▼
┌─────────────────────────────────────┐
│  MotorBridge                         │
│  厂商电机驱动 / CAN 帧发送 / 反馈读取 │
└──────────────┬──────────────────────┘
               │ CAN 总线
               ▼
         7 个达妙电机转动
```

---

## 关节配置（来自 config/robot.yaml）

之前硬件文档里缺失的**关节-电机对应关系**，在这里找到了：

| 关节 | 电机型号 | CAN ID | 反馈 ID | 位置 | 控制参数 |
|---|---|---|---|---|---|
| joint1 | **DM4340P** | 0x01 | 0x11 | 底座旋转 | Kp=120, Kd=8 |
| joint2 | **DM4340P** | 0x02 | 0x12 | 肩部俯仰 | Kp=120, Kd=8 |
| joint3 | **DM4340P** | 0x03 | 0x13 | 大臂 | Kp=120, Kd=8 |
| joint4 | **DM4310** | 0x04 | 0x14 | 小臂 | Kp=18, Kd=2 |
| joint5 | **DM4310** | 0x05 | 0x15 | 腕部俯仰 | Kp=18, Kd=2 |
| joint6 | **DM4310** | 0x06 | 0x16 | 腕部旋转 | Kp=18, Kd=2 |

- 通信方式：串口桥 `/dev/ttyACM0`（达妙 USB2CAN）
- 控制频率：500 Hz
- 反馈 ID 规则：`feedback_id = motor_id + 0x10`

---

## 建议学习路径

### 📚 第零阶段：看文档（推荐新手先看）

> 目标：理解基本概念，不需要硬件

**强烈推荐先看 `docs/` 文件夹的文档！**

1. **`docs/00_新手入门/URDF_入门指南.md`** — 理解什么是 URDF、Link、Joint
2. **`docs/00_新手入门/MeshCat_可视化指南.md`** — 学会用浏览器看 3D 模型
3. **跑 MeshCat 三件套**（无硬件）：
   ```bash
   cd reBotArm_control_py
   python3 example/sim/fk_sim.py    # 正运动学可视化
   python3 example/sim/ik_sim.py    # 逆运动学可视化
   python3 example/sim/traj_sim.py  # 轨迹规划可视化
   ```
4. **`docs/01_项目专用/reBot-DevArm_URDF详解.md`** — 看懂本项目 URDF 为什么这么写
5. **`docs/02_reBotArm_control_py/`** — 理解运动学算法架构
6. **`docs/03_MotorBridge/`** — 理解电机控制架构

**完成第零阶段后，你会对整个系统有清晰的认识，再往下学会轻松很多。**

---

### 第一阶段：理解底层（MotorBridge）

> 目标：搞懂怎么让一个电机转起来

1. 读 `MotorBridge/README.zh-CN.md` — 了解架构
2. 读 `motor_vendors/damiao/src/protocol.rs` — 理解 CAN 协议实现
3. 用 CLI 工具试试扫描电机（需要硬件）：
   ```bash
   motorbridge-cli scan --vendor damiao --transport dm-serial \
     --serial-port /dev/ttyACM0 --serial-baud 921600
   ```

### 第二阶段：单电机控制（reBotArm example 1-4）

> 目标：控制单个电机的位置/速度/力矩

1. `0x01damiao_text.py` — 单电机交互调试（MIT/位置速度/速度模式）
2. `2_zero_and_read.py` — 零位校准 + 实时读取角度
3. `3_mit_control.py` — MIT 模式（位置+速度+Kp+Kd+力矩前馈）
4. `4_pos_vel_control.py` — 位置速度模式

### 第三阶段：运动学（reBotArm example 5-6）

> 目标：理解正/逆运动学

1. `5_fk_test.py` — 输入 6 个关节角 → 算出末端位姿（不需要硬件）
2. `6_ik_test.py` — 输入末端位姿 → 解出关节角（不需要硬件）
3. 读 `reBotArm_control_py/kinematics/` 源码 — 理解 Pinocchio 的用法

### 第四阶段：真机控制（reBotArm example 7-10）

> 目标：让机械臂真正动起来

1. `7_arm_ik_control.py` — 输入末端位置，IK 解算后控制真机
2. `8_arm_traj_control.py` — SE(3) 轨迹规划，平滑运动
3. `9_gravity_compensation.py` — 重力补偿，机械臂可自由拖动
4. `10_gravity_compensation_lock.py` — 重力补偿 + 位置锁定

### 第五阶段：深入源码

> 目标：能修改和扩展

- `reBotArm_control_py/actuator/` — 电机抽象层
- `reBotArm_control_py/kinematics/` — Pinocchio 正/逆运动学封装
- `reBotArm_control_py/dynamics/` — 动力学计算（重力补偿）
- `reBotArm_control_py/trajectory/` — SE(3) 测地线轨迹规划
- `reBotArm_control_py/controllers/` — CLIK 控制器
- `urdf/` — URDF 模型（可用于 ROS/仿真）

### 第六阶段：ROS2 集成

> 目标：把 Python 控制库接入 ROS2 工作流

1. 读 `reBotArmController_ROS2/README_zh.md` — 了解工作区结构和依赖
2. 看 `src/rebotarm_msgs/` — 理解自定义 msg/srv/action 接口
3. 看 `src/rebotarmcontroller/rebotarmcontroller/` — 理解 ROS2 节点如何调用 `reBotArm_control_py`
4. 看 `src/rebotarm_bringup/launch/` — 理解 bringup、driver_only、RViz 的启动方式
5. 真机验证前，先确认 `reBotArm_control_py` 和 `motorbridge` 的 Python 环境都能 import

---

## 环境要求

| 项目 | 要求 |
|---|---|
| Python | 3.10+ |
| 操作系统 | Ubuntu 22.04+（推荐），Windows 可用 WSL2 |
| 硬件通信 | 达妙 USB2CAN 串口桥 或 标准 CAN 接口 |
| 包管理 | uv（推荐）或 pip |

### 安装步骤（无硬件也可学习运动学部分）

```bash
# 1. 安装 uv
curl -LsSf https://astral.sh/uv/install.sh | sh

# 2. 进入项目
cd software/reBotArm_control_py

# 3. 安装依赖
uv sync

# 4. 测试正运动学（不需要硬件）
uv run python example/5_fk_test.py
```

---

## 官方软件路线状态（截至 2026.05.06）

| 模块 | 状态 | 预计时间 |
|---|---|---|
| 组装视频 | ✅ 完成 | 已上线 |
| ROS2 集成 | ✅ 完成 | 代码在独立 ROS2 工作区，不在主仓库内置 |
| Isaac Sim 仿真 | 🚧 进行中 | 2026.06.20 |
| LeRobot 适配 | 🚧 进行中 | wiki 已上线，README_zh 仍标进行中 |
| B601 RS 版硬件 | 🚧 进行中 | 2026.05 |

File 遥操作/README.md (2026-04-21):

# 遥操作系统

## 什么是遥操作？

遥操作（Teleoperation）是指用一台**主动臂（Leader Arm）**手动示教，另一台**从动臂（Follower Arm）**实时跟随复现动作的方式。

在机器人学习领域，遥操作是采集高质量动作数据的标准方案：
```
人手持主动臂 → 做出动作 → 从动臂同步复现 → 记录数据 → 训练 AI 模型
```

这套数据采集流程目前的主流框架是 [LeRobot](https://github.com/huggingface/lerobot)（HuggingFace 出品）。

---

## 本目录的内容

| 子目录 | 内容 |
|---|---|
| `StarArm_102/` | Star Arm 102-LD 遥操作主动臂（git submodule） |

---

## Star Arm 102-LD — 主动臂

**仓库**：[servodevelop/Star-Arm-102](https://github.com/servodevelop/Star-Arm-102)

Star Arm 102-LD 是一款低成本、轻量级的遥操作**主动臂**，用廉价舵机制作，专门用于配合 LeRobot 进行人类示教数据采集。

### 与 reBot Arm B601 的配对关系

| 角色 | 设备 | 驱动方式 |
|---|---|---|
| **主动臂（Leader）** | Star Arm 102-LD | 舵机，手动运动 |
| **从动臂（Follower）** | reBot Arm B601 DM | 达妙减速电机，CAN 总线 |

工作流程：
1. 手持 Star Arm 102-LD 做出动作
2. LeRobot 读取主动臂各关节角度
3. LeRobot 控制 reBot Arm B601 实时跟随
4. 同步录制图像和关节角数据
5. 用采集的数据训练 ACT / Diffusion Policy 等 AI 模型

### Star Arm 102 子目录结构

```
StarArm_102/
├── Hardware/           硬件：CAD 文件（DWG + PDF）+ BOM 清单
├── Lerobot/            软件：LeRobot 兼容 Python 包
│   ├── lerobot-robot-stararm102/       从动臂接口（给 reBot 用的是这个逻辑）
│   ├── lerobot-teleoperator-stararm102/  主动臂接口（Star Arm 102-LD）
│   ├── stararm102.md                   中文使用说明
│   └── stararm102_en.md                英文使用说明
├── ROS2_HUMBLE/        ROS2 + MoveIt2 配置（可选，进阶用）
└── Media/              产品图片
```

---

## 快速上手

### 前提条件

- Python 3.10+
- 已安装 LeRobot：`pip install lerobot`
- reBot Arm B601 通电、CAN 总线连接正常
- Star Arm 102-LD 通过 USB 连接到电脑

### 详细步骤

参考 `StarArm_102/Lerobot/stararm102.md`（中文）或 `stararm102_en.md`（英文）。

LeRobot 官方的 reBot 遥操作教程将在官方 wiki 更新，目前可关注：
- [SeeedStudio Wiki](https://wiki.seeedstudio.com/)
- [LeRobot 官方仓库](https://github.com/huggingface/lerobot)

---

## 更新 submodule

首次克隆本仓库后，需要初始化 submodule：

```bash
git submodule update --init --recursive
```

更新 Star Arm 102 到最新版：

```bash
cd 遥操作/StarArm_102
git pull origin main
cd ../..
git add 遥操作/StarArm_102
git commit -m "更新 StarArm_102 submodule"
```

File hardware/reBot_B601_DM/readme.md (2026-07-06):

# 🤖 reBot DevArm Open Source Hardware Specification

<p align="center">
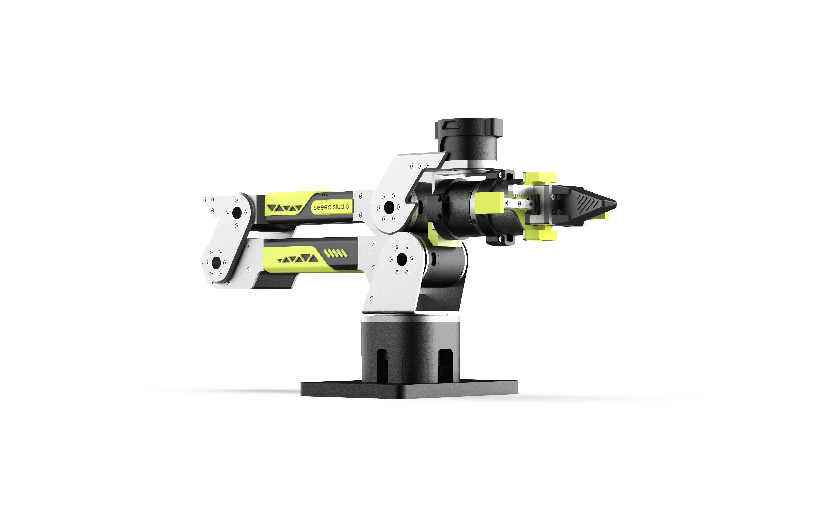
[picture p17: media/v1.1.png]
reBot-DevArm Banner
  
</p>
<p align="center">
  <strong>
    <a href="./readme_zh.md">简体中文</a> &nbsp;|&nbsp;
    <a href="./readme.md">English</a> &nbsp;|&nbsp;
    <a href="./readme_jp.md">日本語</a>&nbsp;|&nbsp;
    <a href="./readme_fr.md">français</a>&nbsp;|&nbsp;
    <a href="./readme_es.md">Español</a>
  </strong>
</p>

| Date | Version | File Name | Changelog |
|---|---|---|---|
|  2026-03-31 | v1.0 |  reBot_B601_DM_v1.0_20260331.step  | Initial upload |
|  2026-04-25 | v1.1 |  reBot_B601_DM_v1.1_20260425.step  | Added Cable Restraint for the 3 end joint motors to prevent loosening and disconnection. Fixed Joint 1 model from 4310 to 4340P. Added CNC part 02_Base_Reinforcement_Part.step at the bottom to enhance base rigidity. |

This BOM is for the reBot Arm B601 DM robotic arm, which uses Damiao 43 series motors. The other version, reBot Arm B601 RS, uses RobStride motors; [see the BOM here](../reBot_B601_RS/README.md).

# 📦 File Structure
*   3D_Printed_Parts/: Step files for all 3D printed parts.
*   Metal_Parts/: Step files for all CNC machined metal parts.
*   Purchased_Parts/: Step files for all purchased components.
*   reBot_B601_DM_v1.1_20260415.step: Full robotic arm assembly file.

# 🛒[Gets All Parts](https://www.seeedstudio.com/reBot-Arm-B601-DM-Bundle.html)
- We offer five kit options:
  - **Arm Body Motor Kit**: Includes only motors and wiring harnesses for the robotic arm.
  - **Arm Body Structural Kit**: Includes only mechanical structural components.
  - **Gripper Complete Kit**: Includes motors, wiring harnesses and structural components for the gripper.
  - **Full Kit**: Includes the complete set of the robotic arm body and gripper.
  - **Pre‑assembled Robotic Arm**: Fully assembled finished robotic arm.

# 📊 Bill of Materials (BOM)

> [!WARNING]
> Declaration: The published BOM does **not** represent the final shipping version from Seeed. This open-source v1.1 is optimized for developers to reproduce at minimal cost, with some non-essential details simplified.
> The final Seeed production version will include metal laser engraving for foolproofing, some 3D printed parts will be replaced with metal for durability, clearances and machining tolerances will be adjusted for factory variation (balancing precision and cost), and custom wiring (e.g., braided sleeve protection) will be added at extra cost. However, the mechanical structure remains identical.

---

## 🖨️ 3D Printed Parts

| Part Description | Image | File Name | Material | Qty | Notes |
|---|---|---|---|---|---|
| Robotic Arm Base Platform |  | 01_BASE_Plate.step | Bambu ABS Black | 1 | 0.4 nozzle, 0.2 layer height, 30% infill |
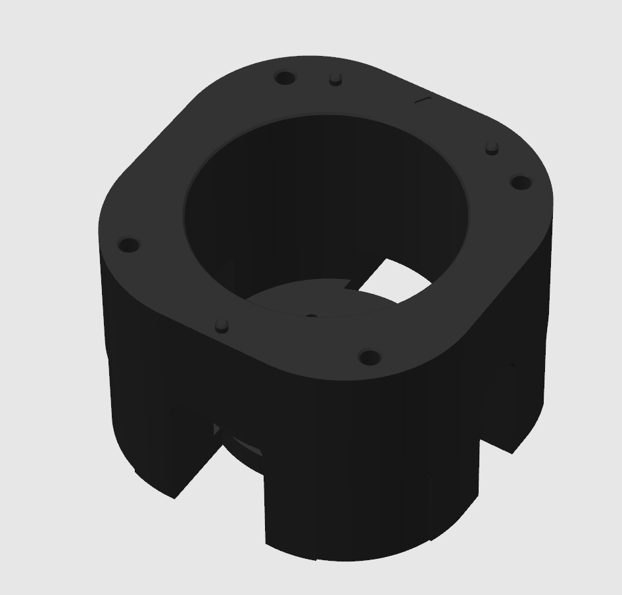
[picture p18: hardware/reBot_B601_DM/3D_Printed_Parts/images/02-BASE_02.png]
| Robotic Arm Base Link |  | 01_BASE_Link.step | Bambu ABS Black | 1 | 0.4 nozzle, 0.2 layer height, 30% infill |
| Upper Arm Left Filler |  | 01_Upper_Arm_Fuller_L.step | Bambu PLA Black & Green | 1 | 0.4 nozzle, 0.2 layer height, 15% infill |
| Upper Arm Right Filler |  | 01_Upper_Arm_Fuller_R.step | Bambu PLA Black & Green | 1 | 0.4 nozzle, 0.2 layer height, 15% infill |
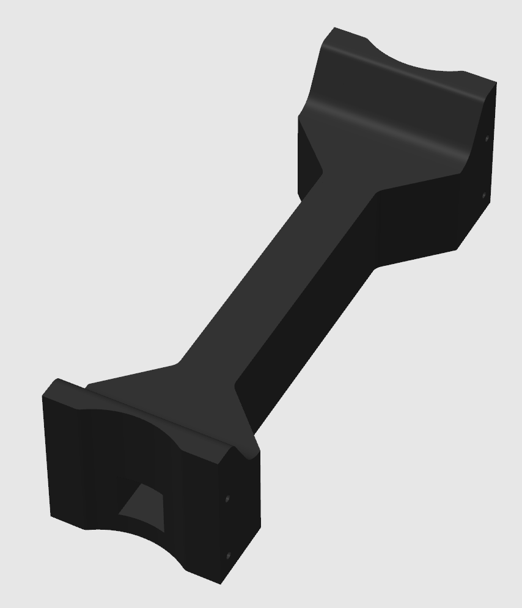
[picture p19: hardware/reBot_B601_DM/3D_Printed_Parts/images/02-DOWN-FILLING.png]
| Upper Arm Center Filler |  | 01_Upper_Arm_Fuller_M.step | Bambu ABS Black | 1 | 0.4 nozzle, 0.2 layer height, 30% infill |
| Upper Arm Horizontal Limit Block |  | 01_Upper_Arm_Limit.step | Bambu ABS Black | 1 | 0.4 nozzle, 0.2 layer height, 30% infill |
| Arm Handle |  | 01_Arm_Handle.step | Bambu ABS Black | 1 | 0.4 nozzle, 0.2 layer height, 30% infill |
| Lower Arm Left Filler |  | 01_Lower_Arm_Filler_L.step | Bambu PLA Black & Green | 1 | 0.4 nozzle, 0.2 layer height, 15% infill |
| Lower Arm Right Filler |  | 01_Lower_Arm_Filler_R.step | Bambu PLA Black & Green | 1 | 0.4 nozzle, 0.2 layer height, 15% infill |
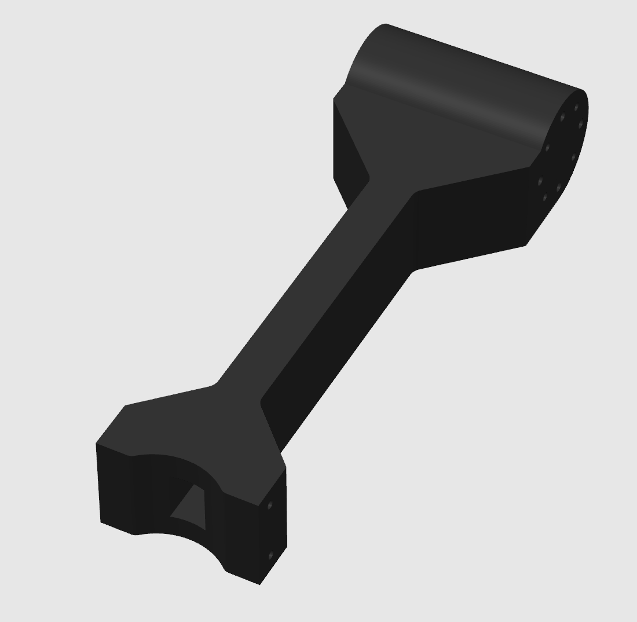
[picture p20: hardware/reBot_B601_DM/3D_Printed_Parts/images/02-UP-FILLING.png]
| Lower Arm Center Filler |  | 01_Lower_Arm_Filler_M.step | Bambu ABS Black | 1 | 0.4 nozzle, 0.2 layer height, 30% infill |
| Upper Arm Cover |  | 01_Upper_Arm_Cover.step | Bambu PLA Green | 1 | 0.4 nozzle, 0.2 layer height, 15% infill |
| Lower Arm Cover |  | 01_Lower_Arm_Cover.step | Bambu PLA Green | 1 | 0.4 nozzle, 0.2 layer height, 15% infill |
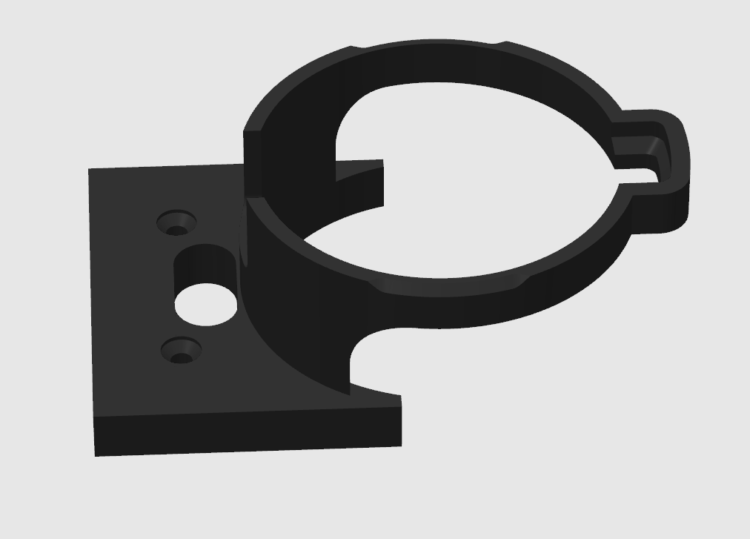
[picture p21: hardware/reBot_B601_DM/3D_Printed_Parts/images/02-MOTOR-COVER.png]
| Motor 5 Protection Cover |  | 01_Motor_Cover.step | Bambu ABS Black | 1 | 0.4 nozzle, 0.2 layer height, 30% infill |
| Gripper Horizontal Limit |  | 01_Lower_Arm_Limit.step | Bambu PLA Green | 1 | 0.4 nozzle, 0.2 layer height, 15% infill |
| Gripper Slider Support Bracket |  | 01-Rail-Bracket.step | Bambu PLA Green | 1 | 0.4 nozzle, 0.2 layer height, 15% infill |
| Gripper Finger |  | 01_Finger.step | Bambu ABS Black | 2 | 0.4 nozzle, 0.2 layer height, 45% infill |
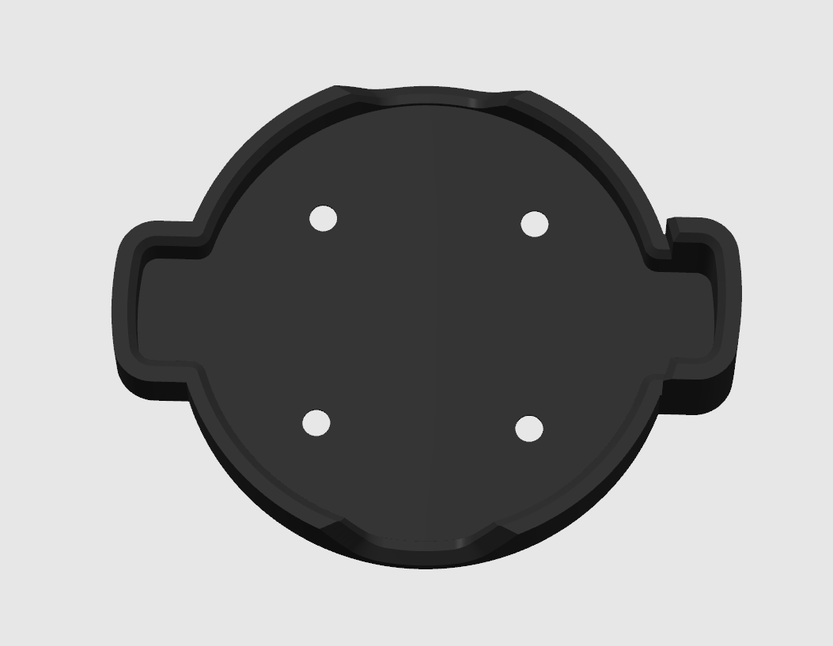
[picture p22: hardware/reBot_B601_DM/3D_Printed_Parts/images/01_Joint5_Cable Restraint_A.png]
| Motor 5 Cable Restraint |  | 01_Joint5_Cable Restraint_A.step | Bambu PLA Green | 1 | 0.4 nozzle, 0.2 layer height, 15% infill |
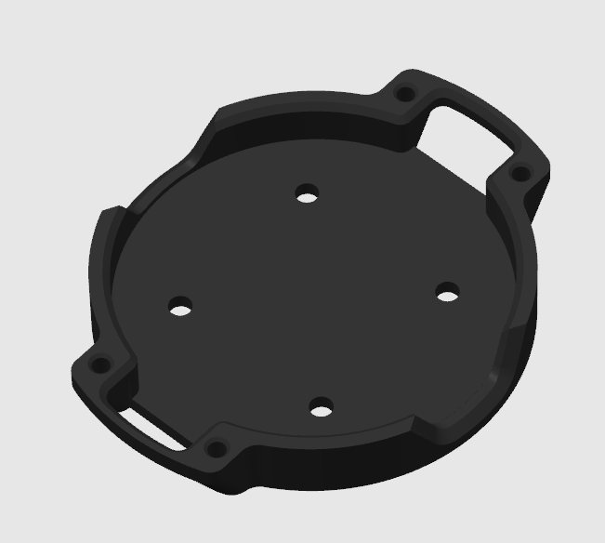
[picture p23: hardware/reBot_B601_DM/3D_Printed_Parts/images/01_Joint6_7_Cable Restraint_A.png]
| Motor 6 & 7 Cable Restraint A |  | 01_Joint6_7_Cable Restraint_A.step | Bambu ABS Black | 2 | 0.4 nozzle, 0.2 layer height, 30% infill |
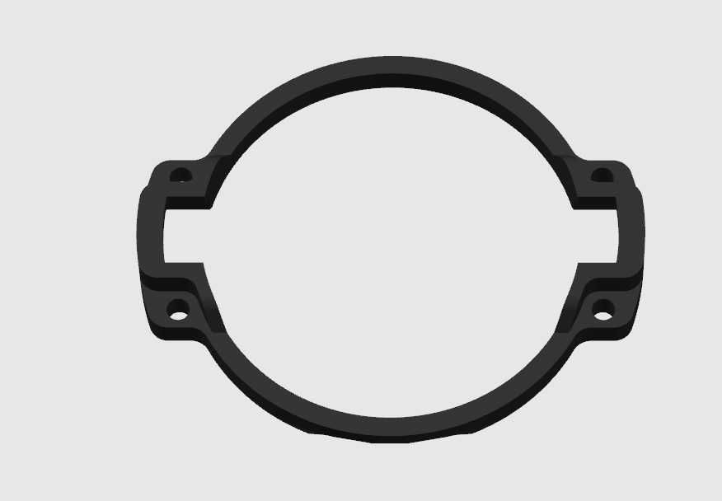
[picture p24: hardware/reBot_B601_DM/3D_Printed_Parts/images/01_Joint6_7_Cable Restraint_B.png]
| Motor 6 & 7 Cable Restraint B |  | 01_Joint6_7_Cable Restraint_B.step | Bambu ABS Black | 2 | 0.4 nozzle, 0.2 layer height, 30% infill |
| - | Reference Price | Average **50$** | | | Price varies by material cost and printing time |

Long-term dragging of Wiring Harness 1 may abrade the motor connector and result in poor electrical contact. Printing the parts listed below can mitigate this risk.

| Part Description | Image | File Name | Material | Qty | Remarks |
| ---- | ---- | ---- | ---- | ---- | ---- |
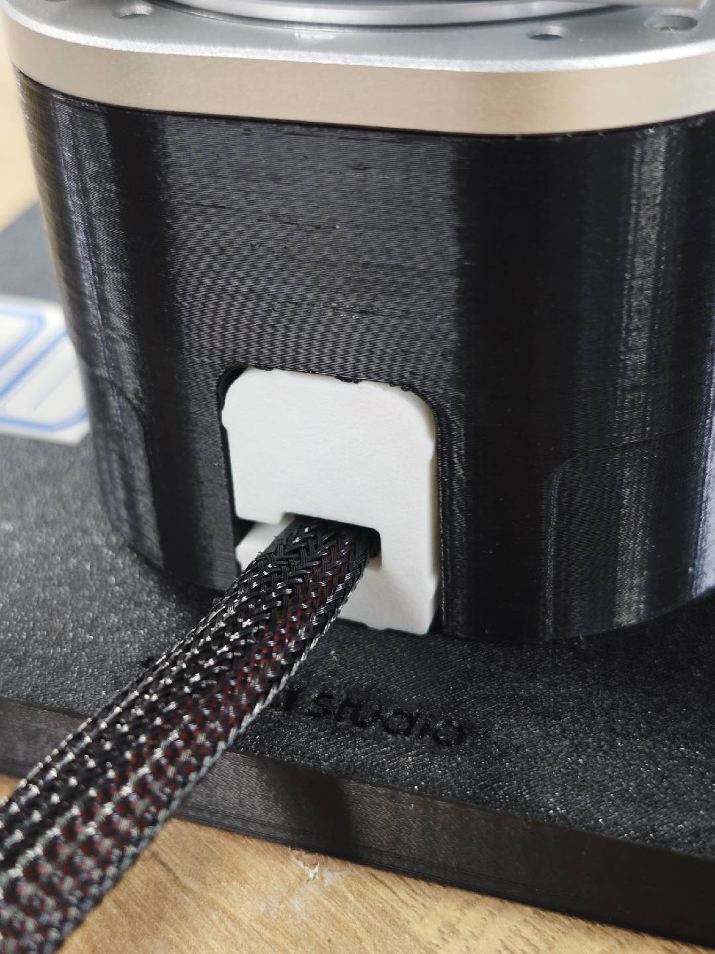
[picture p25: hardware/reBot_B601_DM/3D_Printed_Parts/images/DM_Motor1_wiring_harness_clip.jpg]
| Wiring Harness Clips for Two Sides of Motor 1 |  | `DM_Motor1_wiring_harness_clip.stp` | Bambu Lab Black ABS | 2 | 0.4 mm nozzle, 0.2 mm layer height, 30% infill |

### 🧩 Printing Recommendations
- Layer height: 0.2 mm
- Nozzle: 0.4 mm
- Supports: Add as needed
- Materials: High-temperature and load-bearing parts use ABS with 30–80% infill; may also use nylon or carbon-fiber reinforced materials. Cosmetic parts use PLA with 15% infill.
- Recommended materials for load-bearing parts:

---

## 🔩 CNC Machined Metal Parts

> [!WARNING]
> Some parts that can be replaced with 3D printing are noted in the remarks, which can significantly reduce costs.

| Part Description | Image | File Name | Material | Qty | Machining | Notes |
|---|---|---|---|---|---|---|
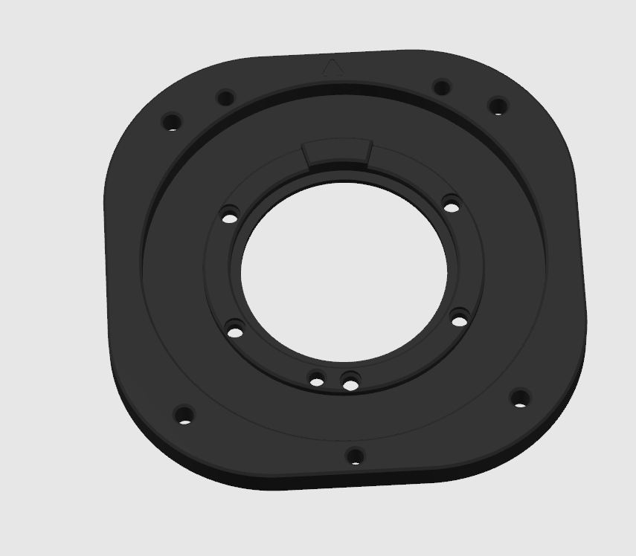
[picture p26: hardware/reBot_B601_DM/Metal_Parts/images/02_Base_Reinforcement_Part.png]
| Motor 1 Bearing Mount |  | 02_Base_Reinforcement_Part.step | Aluminum Alloy 5052 | 1 | CNC | Can be 3D printed in ABS with high infill to reduce cost |
| Motor 1 Rotation Axis |  | 02_Arm_Yaw_Limit.step | Aluminum Alloy 5052 | 1 | CNC | Added yaw angle motion limit |
| Motor 2–5 Front Spacer |  | 02_Motor_Front_Spacer.step | Aluminum Alloy 5052 | 4 | CNC | Can be 3D printed in ABS with 30% infill |
| Motor 2–4 Rear Spacer |  | 02_Motor_Back_Spacer.step | Aluminum Alloy 5052 | 3 | CNC | |
| Motor 2–4 Rear Flange |  | 02_FLANGE.step | Aluminum Alloy 5052 | 3 | CNC | |
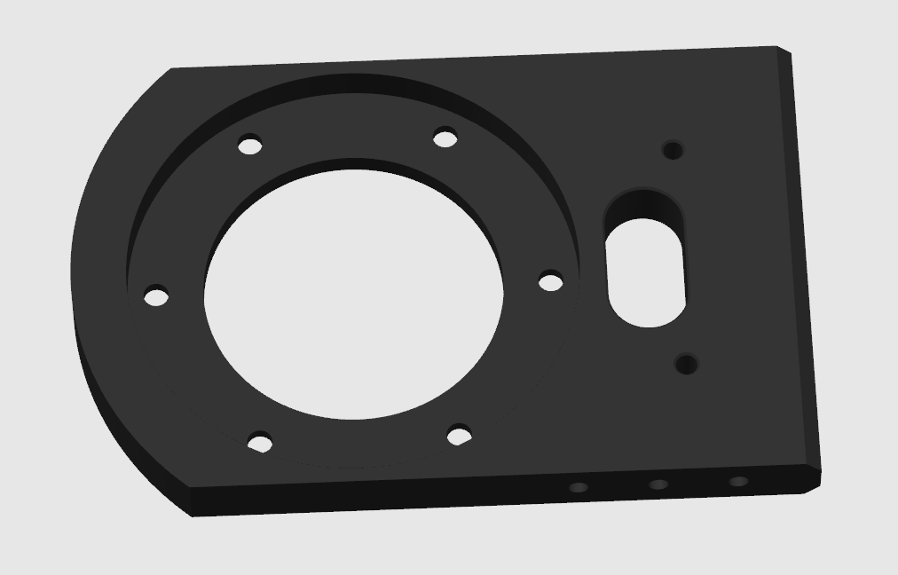
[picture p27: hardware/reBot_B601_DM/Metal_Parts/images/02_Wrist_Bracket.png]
| Wrist Motor 5 Bracket |  | 02_Wrist_Bracket.step | Aluminum Alloy 5052 | 1 | CNC | |
| Gripper Connector A |  | 02_Gripper_Connector_A.step | Aluminum Alloy 5052 | 1 | CNC | |
| Gripper Connector B |  | 02_Gripper_Connector_B.step | Aluminum Alloy 5052 | 1 | CNC | |
| Gripper Slider Metal Bracket |  | 02_Slider_Bracket.step | Aluminum Alloy 5052 | 1 | CNC | Can be 3D printed in ABS with high infill, not recommended for long-term use |
| Slider to Gripper Extension |  | 02_Slider_Extension.step | Aluminum Alloy 5052 | 2 | CNC | |
| Upper-Lower Arm Link Left |  | 02_Lower_Upper_Link_L.step | Aluminum Alloy 5052 | 1 | CNC | |
| Upper-Lower Arm Link Right |  | 02_Lower_Upper_Link_R.step | Aluminum Alloy 5052 | 1 | CNC | |
| Lower Arm-Wrist Link Left |  | 02_Lower_Wrist_Link_L.step | Aluminum Alloy 5052 | 1 | CNC | |
| Lower Arm-Wrist Link Right |  | 02_Lower_Wrist_Link_R.step | Aluminum Alloy 5052 | 1 | CNC | |
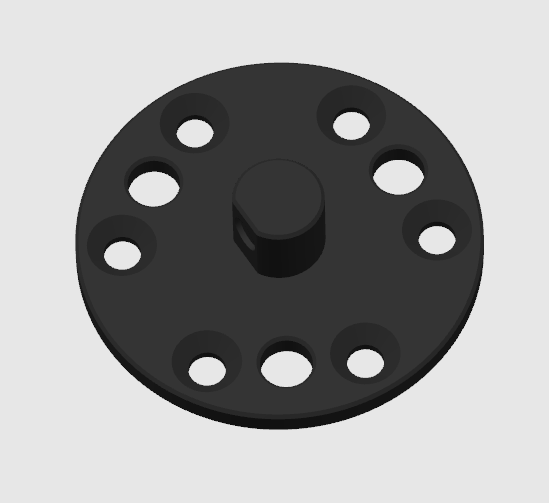
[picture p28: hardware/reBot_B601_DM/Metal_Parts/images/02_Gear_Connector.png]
| Gear Connector |  | 02_Gear_Connector.step | Aluminum Alloy 5052 | 1 | CNC | |
| Rack |  | 02_Rack.step | Aluminum Alloy 5052 | 2 | CNC | |
| Link 1 |  | 03_Link1.step | Aluminum Alloy 5052 | 1 | CNC + Sheet Metal | |
| Link 2 |  | 03_Link2.step | Aluminum Alloy 5052 | 2 | CNC + Sheet Metal | |
| Link 3 Left |  | 03_Link3_L.step | Aluminum Alloy 5052 | 1 | CNC + Sheet Metal | |
| Link 3 Right |  | 03_Link3_R.step | Aluminum Alloy 5052 | 1 | CNC + Sheet Metal | |
| Link 5 |  | 03_Link5.step | Aluminum Alloy 5052 | 1 | CNC + Sheet Metal | |
| - | Market Reference Price | Average **250$** | | | Price varies by aluminum cost, tolerance requirements, lead time |

### 🧩 Machining Specifications
- Key dimension tolerance: ±0.02 mm GB/T1840-M
- Surface finish: Anodizing / Sandblasting
- Mating parts recommended: H7 / interference fit
---

## 🛒 Purchased Parts (Standard Parts)

> [!WARNING]
> Since everyone will need to assemble and tighten the screws themselves, standard hex socket screws have been selected. After prolonged operation, the screws may loosen, which will affect the precision of the robotic arm. For this reason, you are required to purchase additional hot melt glue to perform thread locking on the screws at each joint.

If you have a power drill or similar tools, you may choose to buy lock washers or thread-locking screws instead. However, **it is extremely important** that you use the lowest torque setting when using an electric screwdriver to avoid thread stripping, which will result in irreversible damage.

  | Name | Specification / Model | Quantity | Reference Price | Notes |
  |------|----------|------|----------|------|
  | Brushless motor | DM4310(V4) | 4 | 120 $/unit | [SeeedStudio](https://www.seeedstudio.com/DIP-Servo-Motor-24V-120RPM-Brushless-98-9mm-4P-L56-W56-H46mm-p-6660.html) |
  | Brushless motor | DM4340P(V4) | 3 | 175 $/unit |  [SeeedStudio](https://www.seeedstudio.com/DM4340P-Actuator-p-6663.html)  |
  | CAN-USB driver board |  | 1 | 15 $/unit |   [SeeedStudio](https://www.seeedstudio.com/DM-CAN-USB-Driver-Borad-p-6706.html)   |
  | Bearing | 6707ZZ | 1 | 13 $/unit | [Amazong](https://www.amazon.com/uxcell-35x44x5mm-Shielded-Precision-Lubricated/dp/B0D6WBMW3F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) |
  | Bearing | 6803ZZ | 3 | 13 $/unit | [Amazong](https://www.amazon.com/uxcell-17x26x5mm-Shielded-Precision-Lubricated/dp/B0D54JSWBZ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) |
  | Bearing | AXK5578 | 1 | 12 $/unit | [Amazong](https://www.amazon.com/PZRT-AXK5578-Thrust-Bearings-Washers/dp/B0B3M3RZGW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) |
  | Linear rail | MGN9-170mm | 1 | 23 $/unit | [Amazong](https://www.amazon.com/uxcell-Sliding-Carriage-Bearing-Printers/dp/B0D54L45WM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) |
  | Slider block | MGN9 | 2 | 10 $/unit | [Amazong](https://www.amazon.com/uxcell-Bearing-Sliding-Carriage-Anti-Fall/dp/B0D9QBQDKB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) |
  | Gear | Module 1, boss type, 16 teeth, 6 mm bore | 1 | 44$/unit | [Amazong](https://www.amazon.com/Module-15-Teeth-Finished-Perforation/dp/B0GDSR1LKM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)  |
  | Silicone pad | 30x9x2mm | 1 | 10 $ | [Amazong](https://www.amazon.com/Self-Adhesive-Anti-Sliding-Anti-Scratch-Protectors-Appliances/dp/B0F9KVYXFZ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) |
  | Screw | HM3-12mm screw | 14+ |  | [Amazong](https://www.amazon.com/BNUOK-120pcs-Stainless-Threads-Spanner/dp/B0DJQGMQZM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) |
  | Screw | HM3-25mm screw | 14+ |  | [Amazong](https://www.amazon.com/BNUOK-120pcs-Stainless-Threads-Spanner/dp/B0DJQFGRPQ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)  |
  | Screw | HM3-6mm screw | 16+ |  | [Amazong](https://www.amazon.com/BNUOK-120pcs-Stainless-Threads-Spanner/dp/B0DJQG5YLF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)  |
  | Screw | HM4-75mm set screw | 4+ |  | [Amazong](https://www.amazon.com/iexcell-Partially-Threaded-Thread-Socket/dp/B0DR1NX178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)  |
  | Screw | KM3*12mm screw | 30+ |  |  [Amazong](https://www.amazon.com/Uxcell-a16011300ux0872-M3x12mm-Carbon-Countersunk/dp/B01E6EIC2S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) |
  | Screw | KM3*16mm screw | 34+ |  | [Amazong](https://www.amazon.com/Uxcell-a16011300ux0872-M3x12mm-Carbon-Countersunk/dp/B01E6EIC2S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)  |
  | Screw | KM3*7mm screw | 76+ |  |[Amazong](https://www.amazon.com/Uxcell-a16011300ux0872-M3x12mm-Carbon-Countersunk/dp/B01E6EIC2S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)   |
  | Screw | KM3*9mm screw | 31+ |  |[Amazong](https://www.amazon.com/Uxcell-a16011300ux0872-M3x12mm-Carbon-Countersunk/dp/B01E6EIC2S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)   |
  | Screw | KM3*8mm Socket Micro Profile Head Screw | 31+ |  |[Amazong](https://www.amazon.com/SMALLRIG-Screw-Screws-12pcs-Pack/dp/B01MS60KSY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)   |
  | Screw | KA3*12mm | 72+ |  | [Amazong](https://www.amazon.com/uxcell-Phillips-Tapping-Screws-Silver/dp/B01MXSS95N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)  |
  | Dowel pin | M4*8mm | Several |  | [Amazong](amazon.com/HARFINGTON-Stainless-Cylindrical-Furniture-Installation/dp/B0F6CWL4MP/ref=sr_1_6?crid=2BZ4J412S4QSB&dib=eyJ2IjoiMSJ9.a3kVMi6W355gYKjK1Sl_QFVcJD8x7DTXqxgk66DoY4TnPOEV9TG7AbW7jkNk2USTJrqrb3e5Ve0EeVwHVE-_s-UUP6jFahdiVAqkZGGnuBpVxwA-MCHYQEwThEfygwAc1HVyN1n7Cvr8GAFMvs5AfciRrbUZ8AsSNGc1Obgf8qouOe8NQhyW_Zo7YINX1m3YCuTRiLZCvB6o7XlZtZ4PRh085Bva6AjjnlNOuaiPCtzjvNUtTpyLpGmqoHM165V6onFghMcuOX9RaacnxQNsRoUtKpWPEB8h48nUnUOJ1lg.Hfy_mUj7QFR_kILC4I5RNy6h7HmdswULHg3NmKmK8bU&dib_tag=se&keywords=Dowel%2Bpin%2BM4*7&qid=1776331648&s=industrial&sprefix=dowel%2Bpin%2Bm4%2B%2Cindustrial%2C399&sr=1-6&th=1)  |
  | Dowel pin | M4*12mm | Several |  | [Amazong](amazon.com/HARFINGTON-Stainless-Cylindrical-Furniture-Installation/dp/B0F6CWL4MP/ref=sr_1_6?crid=2BZ4J412S4QSB&dib=eyJ2IjoiMSJ9.a3kVMi6W355gYKjK1Sl_QFVcJD8x7DTXqxgk66DoY4TnPOEV9TG7AbW7jkNk2USTJrqrb3e5Ve0EeVwHVE-_s-UUP6jFahdiVAqkZGGnuBpVxwA-MCHYQEwThEfygwAc1HVyN1n7Cvr8GAFMvs5AfciRrbUZ8AsSNGc1Obgf8qouOe8NQhyW_Zo7YINX1m3YCuTRiLZCvB6o7XlZtZ4PRh085Bva6AjjnlNOuaiPCtzjvNUtTpyLpGmqoHM165V6onFghMcuOX9RaacnxQNsRoUtKpWPEB8h48nUnUOJ1lg.Hfy_mUj7QFR_kILC4I5RNy6h7HmdswULHg3NmKmK8bU&dib_tag=se&keywords=Dowel%2Bpin%2BM4*7&qid=1776331648&s=industrial&sprefix=dowel%2Bpin%2Bm4%2B%2Cindustrial%2C399&sr=1-6&th=1)  |
  | Screwdriver set | Hex key set | 1 | 16$  | [Amazong](amazon.com/Amazon-Basics-Ratcheting-Electronics-Screwdriver/dp/B07V4TFWFZ/ref=sr_1_2?crid=ADAY70RZDSLN&dib=eyJ2IjoiMSJ9.jcLL4o6IXTnPlPfTTzbCZCBuZx2sLkvdUQCwlL58aq__GOyLxVPnwLI0mvGptba_HeVz6ctLQ_ziQw56BMDH9IOaw-4PVJGMktQM74mWficwggm3ckDGyAH-agN_zkB3K0_W-wrS56jfcMYFbZSWhWxr-iSOC4sdXwMGlt4rYGtenyn9yAFYBIHqjU2El5_OAKuspsrF0yQvfyfQPQHs46SClWN8zlSemGVZRuVSU26f0f9yApF6BfWHANKNNhT0Mfb6bQ8oM2XUMvwaazrrKoHeTARuoflVaVZvMU776bs.r8gy_gMINEy0qy4JyK--z-IbPZEv-SWeMGohOOE7M60&dib_tag=se&keywords=Screwdriver+set&qid=1774772499&s=industrial&sprefix=screwdriver+set+%2Cindustrial%2C374&sr=1-2)  |
  |  | XT30 2+2 350mm | 2 | 4 $/cable | Both ends angled |
  |  | XT30 2+2 350mm | 1 | 4 $/cable | One angled end and one straight end |
  |  | XT30 2+2 200mm | 3 | 4 $/cable | Both ends angled |
  |  | XT30 2+2 200mm | 1 | 3 $/cable | Both ends straight |

### About Fixing
You may modify your base freely based on the 3D printed parts we provide. You can also use G-clamps according to the thickness of your desktop.

  | Name | Specification / Model | Quantity | Reference Price | Notes |
  |------|----------|------|----------|------|
  | Woodworking clamp | 6-inch G clamp | 2 | 20 $/unit | [Amazong](https://www.amazon.com/gp/aw/d/B092J1YW2M/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) |

### About Power Supply
The robotic arm is shipped without a power supply by default. You may connect your own battery, or purchase a reliable 24V 14.6A MeanWell power supply made in Taiwan. Additionally, you will need to buy a three-pin plug compliant with local standards and a wiring harness with XT30 female connector.

#### Consumables BOM

| Name | Specification | Qty | Reference Price | Notes | Image |
|:---|:---|:---:|:---:|:---|:---:|
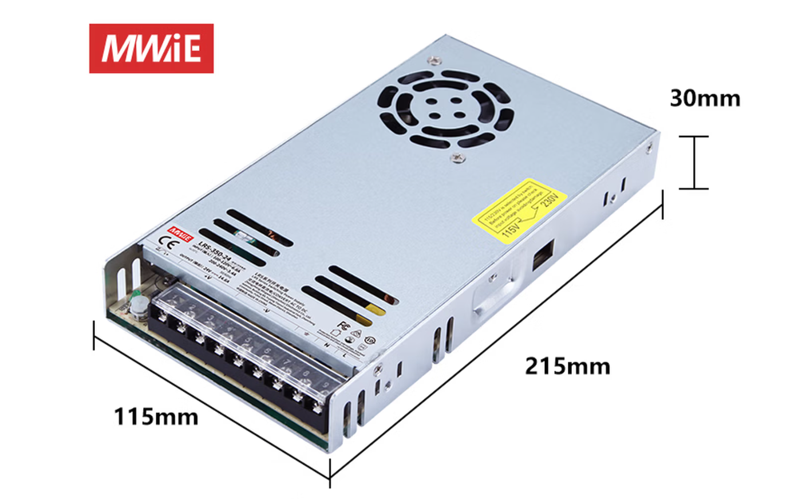
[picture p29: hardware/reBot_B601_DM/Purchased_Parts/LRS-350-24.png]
| Power Supply | LRS-350-24 (24V 14.6A) | 1 | $27.35 | [amazon](https://www.amazon.com/MEAN-WELL-LRS-350-24-350-4W-Switchable/dp/B013ETVO12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) |  |
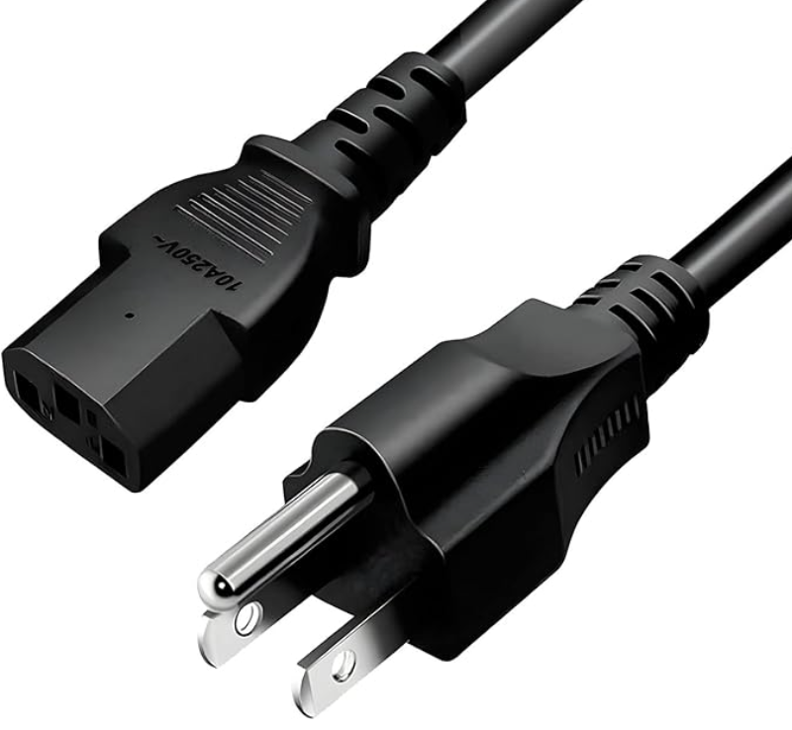
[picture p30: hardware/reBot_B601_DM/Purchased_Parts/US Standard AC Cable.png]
| Power Cord | US Standard AC Cable | 1 | $4.49 | [amazon](https://www.amazon.com/LIFEPOE-Power-3-3ft-Black-3-Prong/dp/B0FK4KPW2G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) |  |
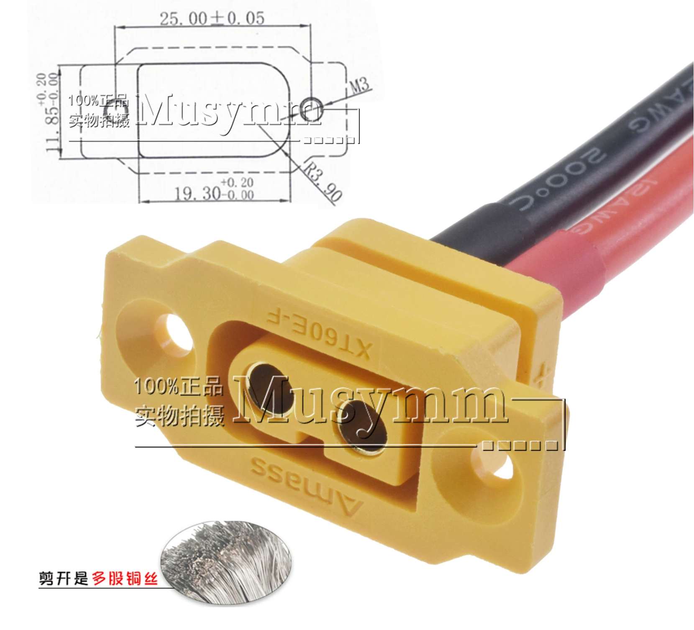
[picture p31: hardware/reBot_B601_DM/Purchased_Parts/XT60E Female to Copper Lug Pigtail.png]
| Output Port | XT60E Fixed Female Connector; XT60E Female + Lug - 10cm; 4mm Lug Hole | 1 | $9.99 | [amazon](https://www.amazon.com/LINSYRC-XT60E-F-Connector-Battery-Quadcopter/dp/B0CQK1P1DP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) |  |
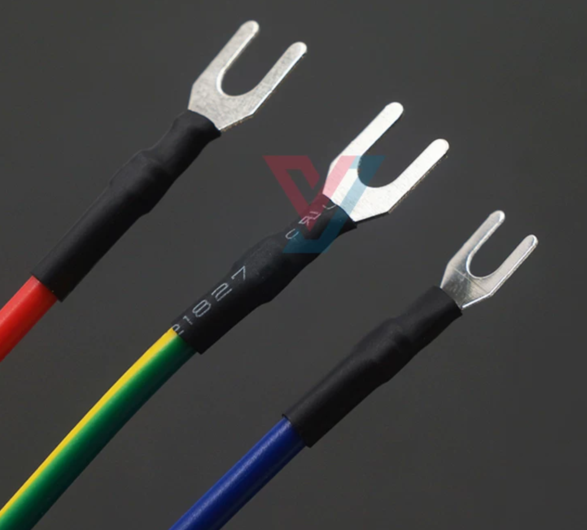
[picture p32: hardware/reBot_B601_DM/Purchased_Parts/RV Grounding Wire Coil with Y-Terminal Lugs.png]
| Power AC Wiring | 1.5mm²; Red, Blue, Yellow x1 each(User must crimp terminals to the wire — pre-crimped leads not included.); 10CM | 3 | $0.99 | [aliexpress](https://www.aliexpress.com/item/1005008648016252.html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) |  |
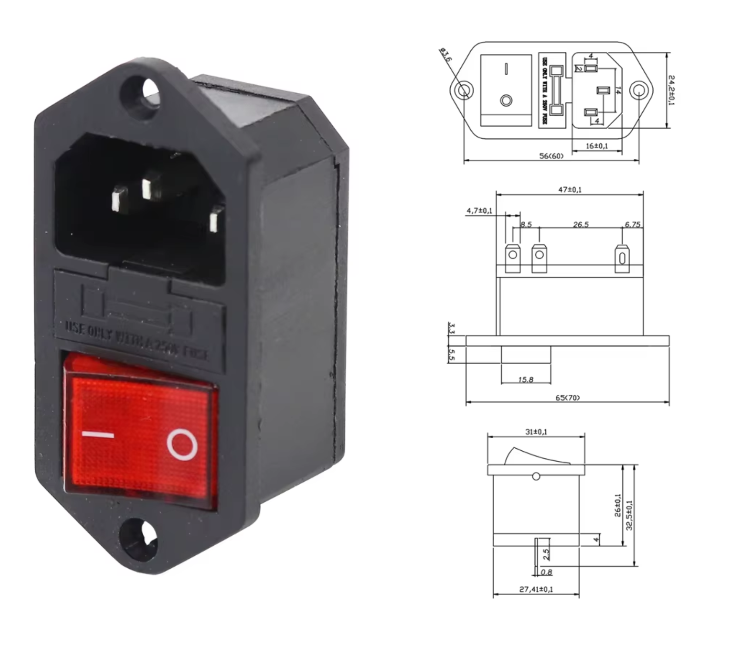
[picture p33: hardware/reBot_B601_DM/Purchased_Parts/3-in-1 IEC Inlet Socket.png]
| 3-in-1 IEC Inlet Socket | Quick-connect type with red switch (Dual Nuts) | 1 | $1.98 | [aliexpress](https://www.aliexpress.com/item/1005005962021242.html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) |  |
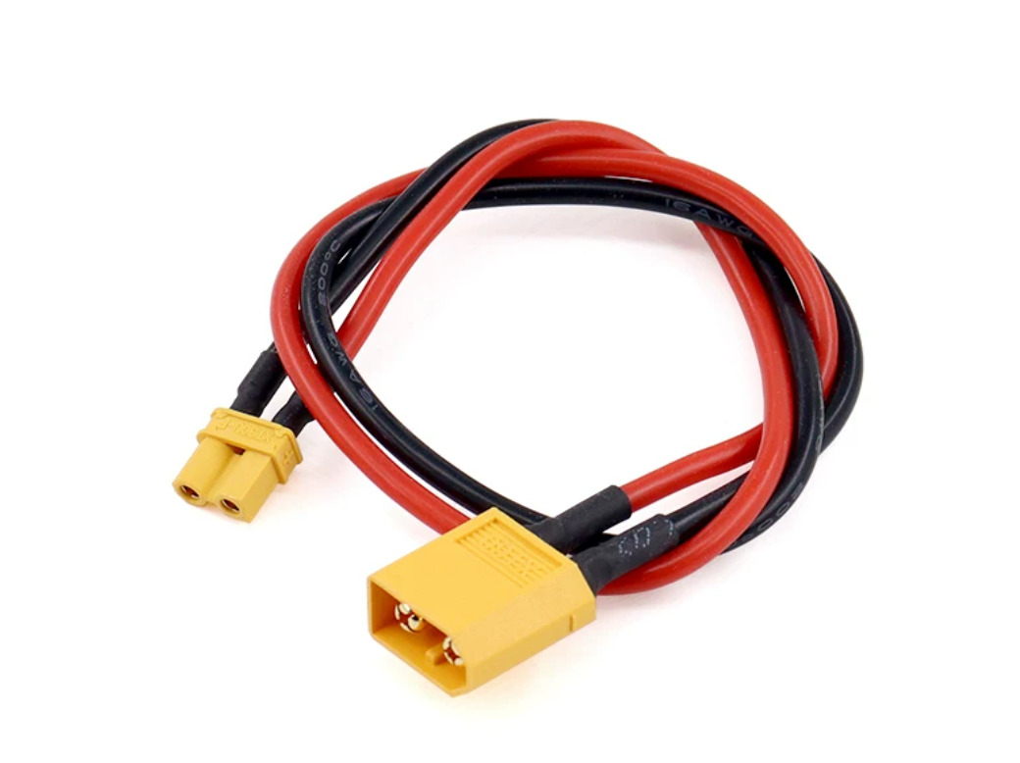
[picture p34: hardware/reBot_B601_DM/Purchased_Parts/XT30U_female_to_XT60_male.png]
| XT30 to XT60 adapter cable plug 12awg | XT30U female to XT60 male, cable length 50cm | 1 | 9.98$ | [amazon](https://www.amazon.com/MEIRIYFA-Extension-Female-Adapter-Silicone/dp/B0B3DMJVV8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) |  |
| 304 Stainless Steel Phillips Countersunk Head Screw | M4x6 | 6 | $0.37 | / | / |
| 304 Stainless Steel Phillips Countersunk Head Screw | M3x8 | 2 | $0.36 | / | / |
| 304 Stainless Steel Phillips Pan Head Screw | M3x8 | 2 | $0.32 | / | / |
| Hex Nut | M3x2.5 | 2 | 2.10 CNY | / | / |

#### Printed Parts BOM

| Name | Image | Qty | Notes |
|:---|:---|:---:|:---|
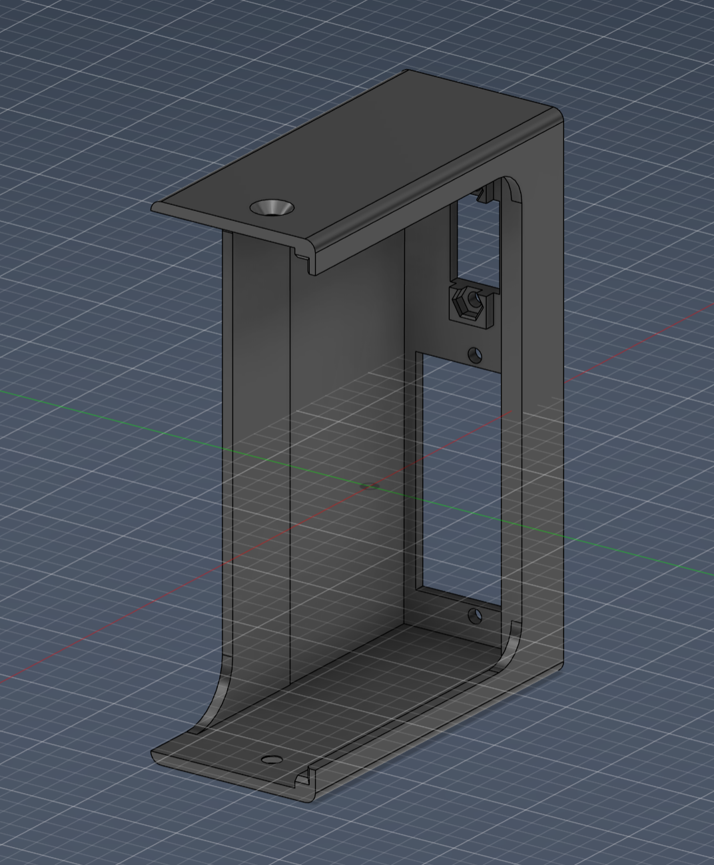
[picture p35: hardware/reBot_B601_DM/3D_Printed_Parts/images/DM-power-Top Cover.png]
| [Front Cover](./3D_Printed_Parts/DM-power-Top%20Cover.stp) |  | 1 | PLA, 0.4mm Nozzle, 0.2mm Layer Height, 30% Infill |
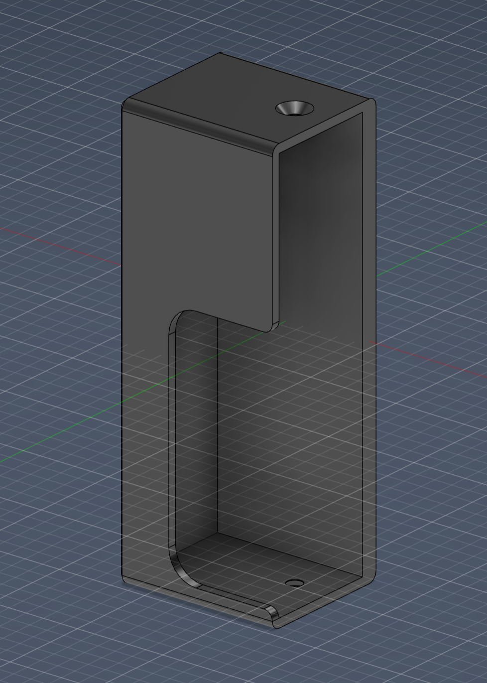
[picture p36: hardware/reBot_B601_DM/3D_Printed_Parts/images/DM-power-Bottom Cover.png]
| [Rear Cover](./3D_Printed_Parts/DM-power-Bottom%20Cover.stp) |  | 1 | PLA, 0.4mm Nozzle, 0.2mm Layer Height, 30% Infill |
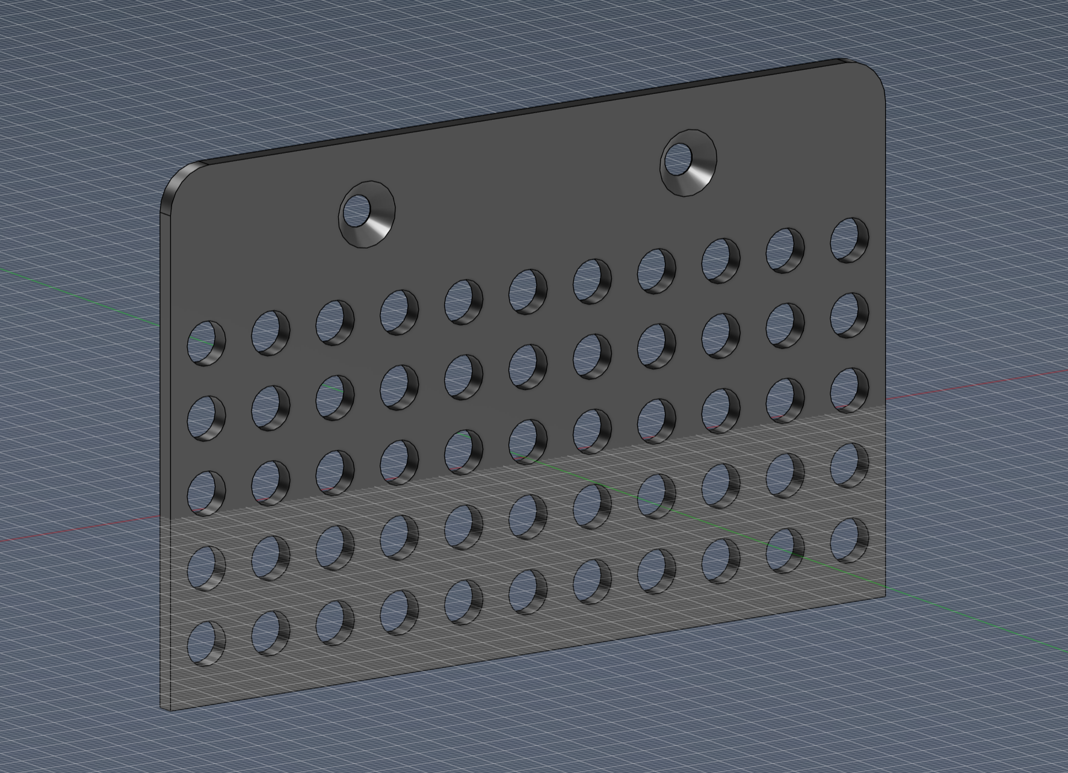
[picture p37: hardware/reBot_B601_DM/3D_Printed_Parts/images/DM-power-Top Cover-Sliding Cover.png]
| [Front Cover Slider](./3D_Printed_Parts/DM-power-Top%20Cover-Sliding%20Cover.stp) |  | 1 | PLA, 0.4mm Nozzle, 0.2mm Layer Height, 30% Infill |

#### Power Supply Assembly

The power supply assembly is divided into two main sections: the Front Cover and the Rear Cover.

> ⚠️ **About the photos below**: The assembly photos (`Assembly_Steps/powerstep_images/`, ~94MB) are too large and are **not uploaded to GitHub in this fork**, so the images in the tables below will appear as missing when viewing this page online.
> - They are kept in local clones and display normally there.
> - To view them online, please refer to the corresponding directory in the upstream repo [Seeed-Projects/reBot-DevArm](https://github.com/Seeed-Projects/reBot-DevArm).
> - STP printable parts, purchased-part reference images, and the textual assembly steps are all fully retained.

##### 1. Front Cover Assembly

| Step | Operation Instructions | Image | Remarks |
|:---:|---|---|---|
| 1-1 | Prepare the parts and printed components required for front shell assembly |  | Check that all parts are complete |
| 1-2 | Wiring sequence instructions for each part; assemble according to the wiring sequence | <br> | Connect strictly according to the wiring sequence |
| 1-3 | Install the XT60 connector |  | Secure with 304 stainless steel Phillips countersunk head screws M3x8 and hex nuts M3x2.5 |
| 1-4 | Install the 3-in-1 IEC socket |  | Secure the 3-in-1 IEC socket with 304 stainless steel Phillips pan head screws M3x8 |
| 1-5 | Internal wiring of the front shell | <br> | Check connections against the wiring sequence diagram |
| 1-6 | Secure both sides of the front shell and the power supply |  | M4x6 304 stainless steel Phillips countersunk head screws x2 |
| 1-7 | Install the sliding cover |  | Push in from the bottom of the power supply |
| 1-8 | Secure the sliding cover |  | M4x6 304 stainless steel Phillips countersunk head screws x2 |

---

##### 2. Rear Shell Assembly

| Step | Operation Instructions | Image | Remarks |
|:---:|---|---|---|
| 2-1 | Prepare the parts and printed components required for rear shell assembly |  | Check accessories for completeness |
| 2-2 | Assemble the rear shell with the power supply |  | Align the position |
| 2-3 | Secure both sides of the rear shell and the power supply |  | M4x6 304 stainless steel Phillips countersunk head screws x2 |

---

##### 3. Overall Completion

| Step | Operation Instructions | Image | Remarks |
|:---:|---|---|---|
| 1 | Power supply solution assembly completed |  | Check that all screws are tightened |

---

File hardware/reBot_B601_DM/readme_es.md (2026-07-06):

# 🤖 Descripción del hardware de código abierto reBot DevArm

<p align="center">
  Banner de reBot-DevArm
</p>
<p align="center">
  <strong>
    <a href="./readme_zh.md">简体中文</a> &nbsp;|&nbsp;
    <a href="./readme.md">English</a> &nbsp;|&nbsp;
    <a href="./readme_jp.md">日本語</a>&nbsp;|&nbsp;
    <a href="./readme_fr.md">français</a>&nbsp;|&nbsp;
    <a href="./readme_es.md">Español</a>
  </strong>
</p>

La BOM actual es la lista de componentes del brazo robótico **reBot Arm B601 DM**, que utiliza los **motores de la serie Damiao 43**. Otra versión, el brazo robótico **reBot Arm B601 RS**, utiliza **motores RobStride**. [Consulte la lista aquí](../reBot_B601_RS/README_zh.md)

# 📦 Estructura de archivos

* `3D_Printed_Parts/`: archivos STEP de todas las piezas impresas en 3D.
* `Metal_Parts/`: archivos STEP de todas las piezas metálicas mecanizadas.
* `Purchased_Parts/`: archivos STEP de todas las piezas compradas.
* `reBot_B601_DM_v1.0_20260425.step`: archivo de ensamblaje completo del brazo robótico.

# 📊 Lista de materiales (BOM)

> [!WARNING]
> Por la presente se declara: la BOM publicada **no** representa la versión final enviada por Seeed. Esta versión de código abierto `v1.1` está destinada a ayudar a los desarrolladores a reproducir el diseño por sí mismos con el menor costo posible y, por lo tanto, reduce algunos gastos innecesarios relacionados con detalles. La versión final enviada por Seeed incluirá detalles que aumentan el costo, como marcas antierrores grabadas con láser en las piezas metálicas, reemplazo de algunas piezas impresas en 3D por piezas metálicas para mayor durabilidad, ajustes de holgura y precisión de mecanizado basados en las tolerancias de las fábricas de procesamiento de metal (un equilibrio entre precisión y costo), personalización especial del arnés de cables (por ejemplo, añadiendo protección con malla trenzada) y otras optimizaciones de detalle. Sin embargo, la configuración estructural sigue siendo la misma.

---

## 🖨️ Piezas impresas en 3D

| Descripción de la pieza | Image | File Name | Material | Quantity | Notes |
|---|---|---|---|---|---|
| Plataforma base del brazo robótico |  | `01_BASE_Plate.step` | Bambu ABS Black | 1 | boquilla 0.4, altura de capa 0.2, relleno 30% |
| Base del brazo robótico |  | `01_BASE_Link.step` | Bambu ABS Black | 1 | boquilla 0.4, altura de capa 0.2, relleno 30% |
| Relleno izquierdo del brazo superior |  | `01_Upper_Arm_Fuller_L.step` | Bambu PLA Black and Green | 1 | boquilla 0.4, altura de capa 0.2, relleno 15% |
| Relleno derecho del brazo superior |  | `01_Upper_Arm_Fuller_R.step` | Bambu PLA Black and Green | 1 | boquilla 0.4, altura de capa 0.2, relleno 15% |
| Relleno central del brazo superior |  | `01_Upper_Arm_Fuller_M.step` | Bambu ABS Black | 1 | boquilla 0.4, altura de capa 0.2, relleno 30% |
| Tope horizontal del brazo superior |  | `01_Upper_Arm_Limit.step` | Bambu ABS Black | 1 | boquilla 0.4, altura de capa 0.2, relleno 30% |
| Asa del brazo robótico |  | `01_Arm_Handle.step` | Bambu ABS Black | 1 | boquilla 0.4, altura de capa 0.2, relleno 30% |
| Relleno izquierdo del antebrazo |  | `01_Lower_Arm_Filler_L.step` | Bambu PLA Black and Green | 1 | boquilla 0.4, altura de capa 0.2, relleno 15% |
| Relleno derecho del antebrazo |  | `01_Lower_Arm_Filler_R.step` | Bambu PLA Black and Green | 1 | boquilla 0.4, altura de capa 0.2, relleno 15% |
| Relleno central del antebrazo |  | `01_Lower_Arm_Filler_M.step` | Bambu ABS Black | 1 | boquilla 0.4, altura de capa 0.2, relleno 30% |
| Cubierta decorativa del brazo superior |  | `01_Upper_Arm_Cover.step` | Bambu PLA Green | 1 | boquilla 0.4, altura de capa 0.2, relleno 15% |
| Cubierta decorativa del antebrazo |  | `01_Lower_Arm_Cover.step` | Bambu PLA Green | 1 | boquilla 0.4, altura de capa 0.2, relleno 15% |
| Cubierta protectora del motor n.º 5 |  | `01_Motor_Cover.step` | Bambu ABS Black | 1 | boquilla 0.4, altura de capa 0.2, relleno 30% |
| Tope horizontal de la pinza |  | `01_Lower_Arm_Limit.step` | Bambu PLA Green | 1 | boquilla 0.4, altura de capa 0.2, relleno 15% |
| Soporte de relleno del deslizador de la pinza |  | `01-Rail-Bracket.step` | Bambu PLA Green | 1 | boquilla 0.4, altura de capa 0.2, relleno 15% |
| Pinza |  | `01_Finger.step` | Bambu ABS Black | 2 | boquilla 0.4, altura de capa 0.2, relleno 45% |
|  | `Reference price` | Promedio **50 $** |  |  | El precio puede variar ligeramente según el precio del material de impresión y el tiempo de impresión de la fábrica |

Si se arrastra el arnés de cableado N.º1 durante su uso prolongado, el conector del motor se desgastará y provocará fallos de contacto. Imprima las piezas que se indican a continuación para reducir este riesgo.

| Descripción de pieza | Imagen | Nombre de archivo | Material | Cantidad | Observaciones |
| ---- | ---- | ---- | ---- | ---- | ---- |
| Clip de arnés de cableado para ambos lados del motor 1 |  | `DM_Motor1_wiring_harness_clip.stp` | ABS negro Bambu Lab | 2 | Boquilla de 0,4 mm, altura de capa 0,2 mm, relleno al 30% |

### 🧩 Recomendaciones de impresión

- Altura de capa: 0.2 mm
- Boquilla: 0.4 mm
- Soportes: añadir según sea necesario
- Materiales: las piezas que necesitan soportar calor y cierta fuerza utilizan material ABS con un relleno del 30% al 80%, y también pueden cambiarse a materiales de nailon / reforzados con fibra de carbono; las piezas de apariencia/decorativas utilizan PLA con un relleno del 15%.
- Materiales recomendados para piezas portantes:

---

## 🔩 Piezas metálicas mecanizadas

> [!WARNING]
> Algunas piezas que pueden sustituirse por impresión 3D se indican en las notas a continuación, lo que puede reducir aún más considerablemente los costos.

| Descripción de la pieza | Image | File Name | Material | Quantity | Manufacturing Process | Notes |
|---|---|---|---|---|---|---|
| Posición de montaje del rodamiento del motor 1 |  | `02_Base_Motor_Shim.step` | Aleación de aluminio 5052 | 1 | CNC | Puede sustituirse por ABS impreso en 3D con mayor relleno para reducir costos |
| Eje giratorio del motor 1 |  | `02_Arm_Yaw_Limit.step` | Aleación de aluminio 5052 | 1 | CNC | Añade límite de movimiento del ángulo de guiñada |
| Espaciador frontal para los motores 2-5 |  | `02_Motor_Front_Spacer.step` | Aleación de aluminio 5052 | 4 | CNC | Puede sustituirse por ABS impreso en 3D, relleno 30%, para reducir costos |
| Espaciador trasero para los motores 2-4 |  | `02_Motor_Back_Spacer.step` | Aleación de aluminio 5052 | 3 | CNC |  |
| Brida trasera para los motores 2-4 |  | `02_FLANGE.step` | Aleación de aluminio 5052 | 3 | CNC |  |
| Base del motor de muñeca 5 |  | `02_Wrist_Bracket.step` | Aleación de aluminio 5052 | 1 | CNC |  |
| Conector de pinza A |  | `02_Gripper_Connector_A.step` | Aleación de aluminio 5052 | 1 | CNC |  |
| Conector de pinza B |  | `02_Gripper_Connector_B.step` | Aleación de aluminio 5052 | 1 | CNC |  |
| Soporte metálico del deslizador de la pinza |  | `02_Slider_Bracket.step` | Aleación de aluminio 5052 | 1 | CNC | Puede sustituirse por ABS impreso en 3D con mayor relleno para reducir costos, pero no se recomienda para uso a largo plazo |
| Deslizador y conector de pinza |  | `02_Slider_Extension.step` | Aleación de aluminio 5052 | 2 | CNC |  |
| Conector izquierdo de la articulación entre brazo superior e inferior |  | `02_Lower_Upper_Link_L.step` | Aleación de aluminio 5052 | 1 | CNC |  |
| Conector derecho de la articulación entre brazo superior e inferior |  | `02_Lower_Upper_Link_R.step` | Aleación de aluminio 5052 | 1 | CNC |  |
| Conector izquierdo de la articulación entre antebrazo y muñeca |  | `02_Lower_Wrist_Link_L.step` | Aleación de aluminio 5052 | 1 | CNC |  |
| Conector derecho de la articulación entre antebrazo y muñeca |  | `02_Lower_Wrist_Link_R.step` | Aleación de aluminio 5052 | 1 | CNC |  |
| Conector de engranaje |  | `02_Gear_Connector.step` | Aleación de aluminio 5052 | 1 | CNC | Para baja carga, puede utilizarse ABS impreso en 3D con relleno del 80% para reducir costos; para alta carga, se recomienda mecanizado CNC en metal |
| Cremallera |  | `02_Rack.step` | Aleación de aluminio 5052 | 2 | CNC |  |
| Link 1 |  | `03-Link1.step` | Aleación de aluminio 5052 | 1 | CNC + chapa metálica |  |
| Link 2 |  | `03-Link2.step` | Aleación de aluminio 5052 | 2 | CNC + chapa metálica |  |
| Link 3 izquierdo |  | `03-Link3_L.step` | Aleación de aluminio 5052 | 1 | CNC + chapa metálica |  |
| Link 3 derecho |  | `03-Link3_R.step` | Aleación de aluminio 5052 | 1 | CNC + chapa metálica |  |
| Link 5 |  | `03-Link5.step` | Aleación de aluminio 5052 | 1 | CNC + chapa metálica |  |
| Precio de referencia de mercado múltiple |  | Promedio **250 $** |  |  |  | El precio puede variar ligeramente debido a las fluctuaciones del costo del aluminio 5052, los requisitos de precisión de mecanizado, el plazo de entrega de la fábrica, etc. |

### 🧩 Instrucciones de mecanizado

- Tolerancia dimensional crítica: ±0.02 mm, GB/T1840-M;
- Tratamiento superficial: anodizado / arenado
- Se recomienda usar H7 / ajuste por interferencia en las piezas de acoplamiento

---

## 🛒 Piezas compradas (piezas estándar)

> [!WARNING]
> Dado que todos tendrán que armar y atornillar por su cuenta, se han seleccionado tornillos hexagonales internos estándar. Después de un funcionamiento prolongado, los tornillos pueden aflojarse y afectar la precisión del brazo robótico.
Por ello, es necesario comprar adicionalmente pegamento termofusible para realizar un tratamiento antiflojamiento en los tornillos de cada articulación. Si disponen de taladro eléctrico u otras herramientas, pueden adquirir tornillos antiflojamiento. Sin embargo, es muy importante usar la potencia mínima con el destornillador eléctrico para evitar dañar la rosca y causar pérdidas irreversibles.

| Name | Specification / Model | Quantity | Reference Price | Notes |
|---|---|---|---|---|
| Motor sin escobillas | DM4310(V4) | 4 | 120 $/unit | [SeeedStudio](https://www.seeedstudio.com/DIP-Servo-Motor-24V-120RPM-Brushless-98-9mm-4P-L56-W56-H46mm-p-6660.html) |
| Motor sin escobillas | DM4340P(V4) | 3 | 175 $/unit |  [SeeedStudio](https://www.seeedstudio.com/DM4340P-Actuator-p-6663.html)  |
| Placa controladora CAN-USB |  | 1 | 15 $/unit | [SeeedStudio](https://www.seeedstudio.com/DM-CAN-USB-Driver-Borad-p-6706.html) |
| Rodamiento | 6707ZZ | 1 | 13 $/unit | [Amazong](https://www.amazon.com/uxcell-35x44x5mm-Shielded-Precision-Lubricated/dp/B0D6WBMW3F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) |
| Rodamiento | 6803ZZ | 3 | 13 $/unit | [Amazong](https://www.amazon.com/uxcell-17x26x5mm-Shielded-Precision-Lubricated/dp/B0D54JSWBZ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) |
| Rodamiento | AXK5578 | 1 | 12 $/unit | [Amazong](https://www.amazon.com/PZRT-AXK5578-Thrust-Bearings-Washers/dp/B0B3M3RZGW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) |
| Riel lineal | MGN9-170mm | 1 | 23 $/unit | [Amazong](https://www.amazon.com/uxcell-Sliding-Carriage-Bearing-Printers/dp/B0D54L45WM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) |
| Bloque deslizante | MGN9 | 2 | 10 $/unit | [Amazong](https://www.amazon.com/uxcell-Bearing-Sliding-Carriage-Anti-Fall/dp/B0D9QBQDKB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) |
| Engranaje | Módulo 1, tipo cubo, 16 dientes, agujero de 6 mm | 1 | 44$/unit | [Amazong](https://www.amazon.com/Module-15-Teeth-Finished-Perforation/dp/B0GDSR1LKM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)  |
| Almohadilla de silicona | 30*9*2mm | 1 | 10 $ | [Amazong](https://www.amazon.com/Self-Adhesive-Anti-Sliding-Anti-Scratch-Protectors-Appliances/dp/B0F9KVYXFZ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) |
| Separador de cobre | M4x50mm | 4 | 8 $ | [Amazong](https://www.amazon.com/Female-Standoff-Quadcopter-Computer-Circuit/dp/B09V2CYDMG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) |
| Tornillo | Tornillo M3*22mm | Several |  | [Amazong](https://www.amazon.com/METERXITY-50-Pack-Stainless-Threaded-Fasteners/dp/B0FLYG7WZ7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)  |
| Tornillo | Tornillo M4*16mm | Several |  | [Amazong](amazon.com/BNUOK-120pcs-Stainless-Threads-Spanner/dp/B0DYNFFB7Q/ref=sr_1_9?crid=W94HLTGLCH57&dib=eyJ2IjoiMSJ9.jg07IMpJdHhW8vR9Ewx53UNnQs_QkpENya6ZqIQWoB6rsXjPLmfWMgAytRy7neNPJJHQzVyP9H7FO5sm9KN9I34nKUQsLRZAG48Rs2rSHwlh2mpA2IPlezHLRlvLN49IIbiHgk5Y63iPwAaxKT27sG3dhyXpf-EABXWIlgUu0FBQ3IIA5kiQDccrsIPN06nR6XBFnNeTu1ogpvhiaZsK7R-VRXcFAsrQvOc4tnzXLlTSM68gR8hBmGYZtQUoOJrRo93U1xfGf7kODnnOqUBWI3VhQIMgnl8Rtt4pl3H7IK0._jHfn0N3UQ0z_FJlv4C8jBXiadkqdO-IHWJzQ3xlm0w&dib_tag=se&keywords=M4*16mm+screw&qid=1774772422&s=industrial&sprefix=m4+16mm+screw%2Cindustrial%2C364&sr=1-9)  |
| Tornillo | Tornillo prisionero M3*8mm | 5 | 5$ | [Amazong](https://www.amazon.com/Headless-Internal-Stainless-Concave-External/dp/B0D8TGXG9D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)  |
| Tornillo | Tornillo avellanado M3*22mm | Several |  |  [Amazong](https://www.amazon.com/Countersunk-DIN7991-Stainless-Threaded-Fasteners/dp/B0CG1PV6SH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) |
| Tornillo | Tornillo avellanado M3*8mm | Several |  | [Amazong](https://www.amazon.com/Countersunk-DIN7991-Stainless-Threaded-Fasteners/dp/B0CG1PV6SH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)  |
| Tornillo | Tornillo avellanado M3*16mm | Several |  |[Amazong](https://www.amazon.com/Countersunk-DIN7991-Stainless-Threaded-Fasteners/dp/B0CG1PV6SH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) |
| Tornillo | Tornillo autorroscante M3*12mm | Several |  | [Amazong](https://www.amazon.com/Countersunk-DIN7991-Stainless-Threaded-Fasteners/dp/B0CG1PV6SH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)  |
| Pasador cilíndrico | M4*8mm | Several |  | [Amazong](https://www.amazon.com/Countersunk-DIN7991-Stainless-Threaded-Fasteners/dp/B0CG1PV6SH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)  |
| Pasador cilíndrico | M4*12mm | Several |  | [Amazong](https://www.amazon.com/Countersunk-DIN7991-Stainless-Threaded-Fasteners/dp/B0CG1PV6SH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)  |
| Juego de destornilladores | Juego de llaves hexagonales | 1 | 16$  | [Amazong](amazon.com/Amazon-Basics-Ratcheting-Electronics-Screwdriver/dp/B07V4TFWFZ/ref=sr_1_2?crid=ADAY70RZDSLN&dib=eyJ2IjoiMSJ9.jcLL4o6IXTnPlPfTTzbCZCBuZx2sLkvdUQCwlL58aq__GOyLxVPnwLI0mvGptba_HeVz6ctLQ_ziQw56BMDH9IOaw-4PVJGMktQM74mWficwggm3ckDGyAH-agN_zkB3K0_W-wrS56jfcMYFbZSWhWxr-iSOC4sdXwMGlt4rYGtenyn9yAFYBIHqjU2El5_OAKuspsrF0yQvfyfQPQHs46SClWN8zlSemGVZRuVSU26f0f9yApF6BfWHANKNNhT0Mfb6bQ8oM2XUMvwaazrrKoHeTARuoflVaVZvMU776bs.r8gy_gMINEy0qy4JyK--z-IbPZEv-SWeMGohOOE7M60&dib_tag=se&keywords=Screwdriver+set&qid=1774772499&s=industrial&sprefix=screwdriver+set+%2Cindustrial%2C374&sr=1-2)  |
|    | XT30 2+2 350mm | 2 | 4 $/cable | Ambos extremos en ángulo |
|    | XT30 2+2 350mm | 1 | 4 $/cable | Un extremo en ángulo y un extremo recto |
|    | XT30 2+2 200mm | 3 | 4 $/cable | Ambos extremos en ángulo |
| Requerido personalizado | XT30 2+2 200mm | 1 | 3 $/cable | Ambos extremos rectos |

### Concernant la fixation
Vous pouvez modifier librement la base à l'aide des pièces imprimées en 3D fournies. Vous pouvez également utiliser des serre-joints en fonction de l'épaisseur de votre plateau de table.

| Désignation | Spécifications / Référence | Quantité | Prix de référence | Remarques |
|---|---|---|---|---|
| Serre-joint à bois | Serre-joint G de 6 pouces | 2 | 20 $/unité | [Amazon](https://www.amazon.com/gp/aw/d/B092J1YW2M/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) |

### Concernant l'alimentation électrique
Le bras robotique est livré sans alimentation d'origine. Vous pouvez brancher votre propre batterie ou acheter une alimentation fiable MeanWell de 24V 14,6A fabriquée à Taïwan. De plus, vous devrez vous procurer une fiche trois broches conforme aux normes locales ainsi qu'un faisceau de câbles équipé d'un connecteur femelle XT30.

| Désignation | Spécifications / Référence | Quantité | Prix de référence | Remarques |
|---|---|---|---|---|
| Alimentation électrique | 24V 14,6A | 1 | 30 $ | [Amazon](https://www.amazon.com/MEAN-WELL-LRS-350-24-350-4W-Switchable/dp/B013ETVO12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) |
| Câble d'alimentation | 12AWG | 1 | 30 $ | [Amazon](https://www.amazon.com/Pinfox-Universal-Appliance-Replacement-Pigtail/dp/B0F5PW5SJG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) |
| Câble d'alimentation | XT30 16AWG | 1 | 9 $ | [Amazon](https://www.amazon.com/RioRand-Connector-Pigtail-Silicone-Aircraft/dp/B0FY2ZCR83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) |

---

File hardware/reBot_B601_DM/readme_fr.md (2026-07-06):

# 🤖 Spécifications Matérielles Open Source du reBot DevArm

<p align="center">
  reBot-DevArm Banner
</p>
<p align="center">
  <strong>
    <a href="./readme_zh.md">简体中文</a> &nbsp;|&nbsp;
    <a href="./readme.md">English</a> &nbsp;|&nbsp;
    <a href="./readme_jp.md">日本語</a>&nbsp;|&nbsp;
    <a href="./readme_fr.md">français</a>&nbsp;|&nbsp;
    <a href="./readme_es.md">Español</a>
  </strong>
</p>

| Date | Version | Nom du fichier | Historique des modifications |
|---|---|---|---|
| 2026-03-31 | v1.0 | reBot_B601_DM_v1.0_20260331.step | Mise en ligne initiale |
| 2026-04-15 | v1.1 | reBot_B601_DM_v1.1_20260415.step | Ajout de colliers de câble pour les 3 moteurs d’articulation terminale afin d’éviter le desserrage et la déconnexion. Correction du modèle de l’articulation 1 de 4310 à 4340P. Ajout de la pièce usinée CNC 02_Base_Reinforcement_Part.step à la base pour renforcer la rigidité. |

Cette nomenclature (BOM) concerne le bras robotique reBot Arm B601 DM, équipé de moteurs Damiao série 43.
L’autre version, reBot Arm B601 RS, utilise des moteurs RobStride ; [voir la nomenclature ici](../reBot_B601_RS/README.md).

# 📦 Structure des fichiers
*   3D_Printed_Parts/ : Fichiers Step de toutes les pièces imprimées en 3D.
*   Metal_Parts/ : Fichiers Step de toutes les pièces métalliques usinées CNC.
*   Purchased_Parts/ : Fichiers Step de tous les composants standard achetés.
*   reBot_B601_DM_v1.1_20260415.step : Fichier d’assemblage complet du bras robotique.

# 🛒 [Obtenir toutes les pièces](https://www.seeedstudio.com/reBot-Arm-B601-DM-Bundle.html)
- Nous proposons cinq options de kit :
  - **Kit Moteurs du Bras** : Inclut uniquement les moteurs et faisceaux de câbles du bras robotique.
  - **Kit Structure du Bras** : Inclut uniquement les composants mécaniques de structure.
  - **Kit Complet Préhenseur** : Inclut moteurs, faisceaux de câbles et composants de structure du préhenseur.
  - **Kit Complet** : Inclut l’ensemble du corps du bras robotique et du préhenseur.
  - **Bras Robotique Pré-assemblé** : Bras robotique fini entièrement assemblé.

# 📊 Nomenclature (BOM)

> [!WARNING]
> Déclaration : La nomenclature publiée **ne représente pas** la version finale livrée par Seeed.
> Cette version open source v1.1 est optimisée pour que les développeurs puissent la reproduire à coût minimal, avec certains détails non essentiels simplifiés.
> La version de production finale Seeed comprendra une gravure laser métallique pour éviter les erreurs de montage, certaines pièces imprimées en 3D seront remplacées par du métal pour plus de durabilité, les jeux et tolérances d’usinage seront ajustés pour les variations industrielles (équilibre entre précision et coût), et un câblage personnalisé (avec gaine tressée par exemple) sera ajouté avec un coût supplémentaire. Cependant, la structure mécanique reste identique.

---

## 🖨️ Pièces imprimées en 3D

| Description de la pièce | Image | Nom du fichier | Matériau | Qté | Notes |
|---|---|---|---|---|---|
| Plaque de base du bras robotique |  | 01_BASE_Plate.step | Bambu ABS Noir | 1 | Buse 0.4, hauteur de couche 0.2, remplissage 30% |
| Liaison de base du bras robotique |  | 01_BASE_Link.step | Bambu ABS Noir | 1 | Buse 0.4, hauteur de couche 0.2, remplissage 30% |
| Garniture côté gauche du bras supérieur |  | 01_Upper_Arm_Fuller_L.step | Bambu PLA Noir & Vert | 1 | Buse 0.4, hauteur de couche 0.2, remplissage 15% |
| Garniture côté droit du bras supérieur |  | 01_Upper_Arm_Fuller_R.step | Bambu PLA Noir & Vert | 1 | Buse 0.4, hauteur de couche 0.2, remplissage 15% |
| Garniture centrale du bras supérieur |  | 01_Upper_Arm_Fuller_M.step | Bambu ABS Noir | 1 | Buse 0.4, hauteur de couche 0.2, remplissage 30% |
| Butée de limite horizontale du bras supérieur |  | 01_Upper_Arm_Limit.step | Bambu ABS Noir | 1 | Buse 0.4, hauteur de couche 0.2, remplissage 30% |
| Poignée du bras |  | 01_Arm_Handle.step | Bambu ABS Noir | 1 | Buse 0.4, hauteur de couche 0.2, remplissage 30% |
| Garniture côté gauche du bras inférieur |  | 01_Lower_Arm_Filler_L.step | Bambu PLA Noir & Vert | 1 | Buse 0.4, hauteur de couche 0.2, remplissage 15% |
| Garniture côté droit du bras inférieur |  | 01_Lower_Arm_Filler_R.step | Bambu PLA Noir & Vert | 1 | Buse 0.4, hauteur de couche 0.2, remplissage 15% |
| Garniture centrale du bras inférieur |  | 01_Lower_Arm_Filler_M.step | Bambu ABS Noir | 1 | Buse 0.4, hauteur de couche 0.2, remplissage 30% |
| Cache du bras supérieur |  | 01_Upper_Arm_Cover.step | Bambu PLA Vert | 1 | Buse 0.4, hauteur de couche 0.2, remplissage 15% |
| Cache du bras inférieur |  | 01_Lower_Arm_Cover.step | Bambu PLA Vert | 1 | Buse 0.4, hauteur de couche 0.2, remplissage 15% |
| Cache de protection du moteur 5 |  | 01_Motor_Cover.step | Bambu ABS Noir | 1 | Buse 0.4, hauteur de couche 0.2, remplissage 30% |
| Butée de limite horizontale du préhenseur |  | 01_Lower_Arm_Limit.step | Bambu PLA Vert | 1 | Buse 0.4, hauteur de couche 0.2, remplissage 15% |
| Support de coulisseau du préhenseur |  | 01-Rail-Bracket.step | Bambu PLA Vert | 1 | Buse 0.4, hauteur de couche 0.2, remplissage 15% |
| Doigt de préhenseur |  | 01_Finger.step | Bambu ABS Noir | 2 | Buse 0.4, hauteur de couche 0.2, remplissage 45% |
| Collier de câble du moteur 5 |  | 01_Joint5_Cable Restraint_A.step | Bambu PLA Vert | 1 | Buse 0.4, hauteur de couche 0.2, remplissage 15% |
| Collier de câble A pour moteurs 6 & 7 |  | 01_Joint6_7_Cable Restraint_A.step | Bambu ABS Noir | 2 | Buse 0.4, hauteur de couche 0.2, remplissage 30% |
| Collier de câble B pour moteurs 6 & 7 |  | 01_Joint6_7_Cable Restraint_B.step | Bambu ABS Noir | 2 | Buse 0.4, hauteur de couche 0.2, remplissage 30% |
| - | Prix de référence | Moyenne **50$** | | | Prix variable selon coût du matériau et temps d’impression |

Lors d’une utilisation prolongée, le tirage répété du faisceau de câbles 1 provoque l’usure du connecteur du moteur et entraîne des défauts de contact. Imprimez les pièces listées ci-dessous pour limiter ce risque.

| Désignation de la pièce | Image | Nom du fichier | Matériau | Quantité | Remarques |
| ---- | ---- | ---- | ---- | ---- | ---- |
| Attache de faisceau pour les deux faces du moteur 1 |  | `DM_Motor1_wiring_harness_clip.stp` | ABS noir Bambu Lab | 2 | Buse 0,4 mm, hauteur de couche 0,2 mm, remplissage 30 % |

## 📷 Support de caméra compatible

| Description de la pièce | Image | Nom du fichier | Matériau | Qté | Notes |
|---|---|---|---|---|---|
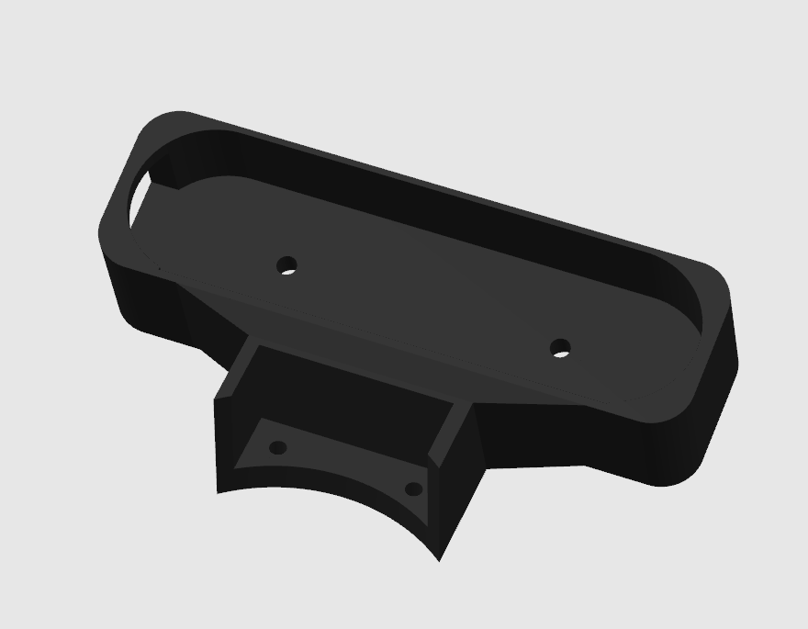
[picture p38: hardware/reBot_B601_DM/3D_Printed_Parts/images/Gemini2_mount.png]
| [Orbbec Gemini2](https://www.seeedstudio.com/Orbbec-Gemini-2-3D-Camera-p-6464.html) |  | Gemini2_mount.step | Bambu ABS Noir | 1 | Buse 0.4, hauteur de couche 0.2, remplissage 30% |

### 🧩 Recommandations d’impression
- Hauteur de couche : 0.2 mm
- Buse : 0.4 mm
- Supports : Ajouter si nécessaire
- Matériaux : Pièces résistant à la chaleur et aux charges : ABS avec remplissage 30–80% ; nylon ou matériaux renforcés de fibre de carbone également possibles. Pièces esthétiques : PLA avec remplissage 15%.
- Matériaux recommandés pour les pièces sous charge :

---

## 🔩 Pièces métalliques usinées CNC

> [!WARNING]
> Certaines pièces pouvant être remplacées par impression 3D sont indiquées en note, ce qui permet de réduire significativement les coûts.

| Description de la pièce | Image | Nom du fichier | Matériau | Qté | Usinage | Notes |
|---|---|---|---|---|---|---|
| Support de palier du moteur 1 |  | 02_Base_Reinforcement_Part.step | Alliage d’aluminium 5052 | 1 | CNC | Peut être imprimé en 3D en ABS avec fort remplissage pour réduire les coûts |
| Axe de rotation du moteur 1 avec butée |  | 02_Arm_Yaw_Limit.step | Alliage d’aluminium 5052 | 1 | CNC | Ajout de limite de mouvement en lacet |
| Entretoise avant moteurs 2–5 |  | 02_Motor_Front_Spacer.step | Alliage d’aluminium 5052 | 4 | CNC | Peut être imprimé en 3D en ABS avec remplissage 30% |
| Entretoise arrière moteurs 2–4 |  | 02_Motor_Back_Spacer.step | Alliage d’aluminium 5052 | 3 | CNC | |
| Bride arrière moteurs 2–4 |  | 02_FLANGE.step | Alliage d’aluminium 5052 | 3 | CNC | |
| Support du moteur poignet 5 |  | 02_Wrist_Bracket.step | Alliage d’aluminium 5052 | 1 | CNC | |
| Raccord préhenseur A |  | 02_Gripper_Connector_A.step | Alliage d’aluminium 5052 | 1 | CNC | |
| Raccord préhenseur B |  | 02_Gripper_Connector_B.step | Alliage d’aluminium 5052 | 1 | CNC | |
| Support métallique de coulisseau préhenseur |  | 02_Slider_Bracket.step | Alliage d’aluminium 5052 | 1 | CNC | Peut être imprimé en 3D en ABS avec fort remplissage, non recommandé pour une utilisation prolongée |
| Extension coulisseau-préhenseur |  | 02_Slider_Extension.step | Alliage d’aluminium 5052 | 2 | CNC | |
| Liaison gauche bras supérieur-bras inférieur |  | 02_Lower_Upper_Link_L.step | Alliage d’aluminium 5052 | 1 | CNC | |
| Liaison droite bras supérieur-bras inférieur |  | 02_Lower_Upper_Link_R.step | Alliage d’aluminium 5052 | 1 | CNC | |
| Liaison gauche bras inférieur-poignet |  | 02_Lower_Wrist_Link_L.step | Alliage d’aluminium 5052 | 1 | CNC | |
| Liaison droite bras inférieur-poignet |  | 02_Lower_Wrist_Link_R.step | Alliage d’aluminium 5052 | 1 | CNC | |
| Raccord de pignon |  | 02_Gear_Connector.step | Alliage d’aluminium 5052 | 1 | CNC | |
| Rack |  | 02_Rack.step | Alliage d’aluminium 5052 | 2 | CNC | |
| Liaison 1 |  | 03_Link1.step | Alliage d’aluminium 5052 | 1 | CNC + tôlerie | |
| Liaison 2 |  | 03_Link2.step | Alliage d’aluminium 5052 | 2 | CNC + tôlerie | |
| Liaison 3 gauche |  | 03_Link3_L.step | Alliage d’aluminium 5052 | 1 | CNC + tôlerie | |
| Liaison 3 droite |  | 03_Link3_R.step | Alliage d’aluminium 5052 | 1 | CNC + tôlerie | |
| Liaison 5 |  | 03_Link5.step | Alliage d’aluminium 5052 | 1 | CNC + tôlerie | |
| - | Prix de référence marché | Moyenne **250$** | | | Prix variable selon coût de l’aluminium, exigences de tolérance, délais |

### 🧩 Spécifications d’usinage
- Tolérance dimensionnelle clé : ±0.02 mm GB/T1840-M
- Finition de surface : Anodisation / sablage
- Pièces d’assemblage recommandées : ajustement H7 / ajustement serré

---

## 🛒 Pièces achetées (pièces standard)

> [!WARNING]
> Comme chacun devra assembler et serrer les vis soi-même, des vis hexagonales intérieures standard ont été sélectionnées. Après un fonctionnement prolongé, les vis peuvent se desserrer, ce qui affecte la précision du bras robotique. Pour cette raison, vous devez acheter en plus de la colle chaude pour effectuer un freinage fileté sur les vis de chaque articulation.

Si vous disposez d’une perceuse électrique ou d’outils similaires, vous pouvez choisir d’acheter des rondelles freins ou des vis freins filetées à la place. Cependant, **il est extrêmement important** d’utiliser le réglage de couple le plus bas avec un tournevis électrique pour éviter d’arracher les filets, ce qui entraînerait des dommages irréversibles.

| Nom | Spécification / Modèle | Quantité | Prix de référence | Notes |
|---|---|---|---|---|
| Moteur sans balais | DM4310(V4) | 4 | 120 $/unité | [SeeedStudio](https://www.seeedstudio.com/DIP-Servo-Motor-24V-120RPM-Brushless-98-9mm-4P-L56-W56-H46mm-p-6660.html) |
| Moteur sans balais | DM4340P(V4) | 3 | 175 $/unité | [SeeedStudio](https://www.seeedstudio.com/DM4340P-Actuator-p-6663.html) |
| Carte d’interface CAN-USB | - | 1 | 15 $/unité | [SeeedStudio](https://www.seeedstudio.com/DM-CAN-USB-Driver-Borad-p-6706.html) |
| Palier | 6707ZZ | 1 | 13 $/unité | Amazon |
| Palier | 6803ZZ | 3 | 13 $/unité | Amazon |
| Palier | AXK5578 | 1 | 12 $/unité | Amazon |
| Rail linéaire | MGN9-170mm | 1 | 23 $/unité | Amazon |
| Bloc coulissant | MGN9 | 2 | 10 $/unité | Amazon |
| Pignon | Module 1, type moyeu, 16 dents, alésage 6 mm | 1 | 44 $/unité | Amazon |
| Patin en silicone | 30x9x2mm | 1 | 10 $ | Amazon |
| Vis | HM3-12mm | 14+ | - | Amazon |
| Vis | HM3-25mm | 14+ | - | Amazon |
| Vis | HM3-6mm | 16+ | - | Amazon |
| Vis | HM4-75mm sans tête | 4+ | - | Amazon |
| Vis | KM3×12mm fraisée | 30+ | - | Amazon |
| Vis | KM3×16mm fraisée | 34+ | - | Amazon |
| Vis | KM3×7mm fraisée | 76+ | - | Amazon |
| Vis | KM3×9mm fraisée | 31+ | - | Amazon |
| Vis | KM3×8mm fraisée à tête très basse | 31+ | - | Amazon |
| Vis | KA3×12mm tête bombée | 72+ | - | Amazon |
| Goupille cylindrique | M4×8mm | Plusieurs | - | Amazon |
| Goupille cylindrique | M4×12mm | Plusieurs | - | Amazon |
| Jeu de tournevis | Jeu de clés hexagonales | 1 | 16 $ | Amazon |
|  | XT30 2+2 350mm | 2 | 4 $/câble | Deux extrémités coudées |
|  | XT30 2+2 350mm | 1 | 4 $/câble | Une extrémité coudée, une droite |
|  | XT30 2+2 200mm | 3 | 4 $/câble | Deux extrémités coudées |
|  | XT30 2+2 200mm | 1 | 3 $/câble | Deux extrémités droites |

### Concernant la fixation
Vous pouvez modifier librement la base à l'aide des pièces imprimées en 3D fournies. Vous pouvez également utiliser des serre-joints en fonction de l'épaisseur de votre plateau de table.

| Désignation | Spécifications / Référence | Quantité | Prix de référence | Remarques |
|---|---|---|---|---|
| Serre-joint à bois | Serre-joint G de 6 pouces | 2 | 20 $/unité | [Amazon](https://www.amazon.com/gp/aw/d/B092J1YW2M/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) |

### Concernant l'alimentation électrique
Le bras robotique est livré sans alimentation d'origine. Vous pouvez brancher votre propre batterie ou acheter une alimentation fiable MeanWell de 24V 14,6A fabriquée à Taïwan. De plus, vous devrez vous procurer une fiche trois broches conforme aux normes locales ainsi qu'un faisceau de câbles équipé d'un connecteur femelle XT30.

| Désignation | Spécifications / Référence | Quantité | Prix de référence | Remarques |
|---|---|---|---|---|
| Alimentation électrique | 24V 14,6A | 1 | 30 $ | [Amazon](https://www.amazon.com/MEAN-WELL-LRS-350-24-350-4W-Switchable/dp/B013ETVO12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) |
| Câble d'alimentation | 12AWG | 1 | 30 $ | [Amazon](https://www.amazon.com/Pinfox-Universal-Appliance-Replacement-Pigtail/dp/B0F5PW5SJG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) |
| Câble d'alimentation | XT30 16AWG | 1 | 9 $ | [Amazon](https://www.amazon.com/RioRand-Connector-Pigtail-Silicone-Aircraft/dp/B0FY2ZCR83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) |

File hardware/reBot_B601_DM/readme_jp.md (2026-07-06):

# 🤖 reBot DevArm オープンソースハードウェア仕様書

<p align="center">
  reBot-DevArm バナー
</p>
<p align="center">
  <strong>
    <a href="./readme_zh.md">简体中文</a> &nbsp;|&nbsp;
    <a href="./readme.md">English</a> &nbsp;|&nbsp;
    <a href="./readme_jp.md">日本語</a>&nbsp;|&nbsp;
    <a href="./readme_fr.md">français</a>&nbsp;|&nbsp;
    <a href="./readme_es.md">Español</a>
  </strong>
</p>

| 日付 | バージョン | ファイル名 | 変更履歴 |
|---|---|---|---|
| 2026-03-31 | v1.0 | reBot_B601_DM_v1.0_20260331.step | 初回アップロード |
| 2026-04-15 | v1.1 | reBot_B601_DM_v1.1_20260415.step | エンドジョイント3つのモーターにケーブル拘束を追加し、緩みや外れを防止。ジョイント1のモデルを4310から4340Pに修正。ベース剛性を高めるため、底部にCNCパーツ 02_Base_Reinforcement_Part.step を追加。 |

このBOMは、大疆43シリーズモーターを使用する reBot Arm B601 DM ロボットアーム用です。もう一方のバージョンである reBot Arm B601 RS は RobStride モーターを使用しています。[BOMはこちら](../reBot_B601_RS/README.md)をご覧ください。

# 📦 ファイル構成
*   3D_Printed_Parts/: すべての3Dプリント部品のStepファイル。
*   Metal_Parts/: すべてのCNC加工金属部品のStepファイル。
*   Purchased_Parts/: すべての購入部品のStepファイル。
*   reBot_B601_DM_v1.1_20260415.step: ロボットアームのフルアセンブリファイル。

# 🛒[全部品を入手](https://www.seeedstudio.com/reBot-Arm-B601-DM-Bundle.html)
- 5種類のキットオプションを提供しています：
  - **アームボディモーターキット**: ロボットアーム用のモーターと配線ハーネスのみを含む。
  - **アームボディ構造キット**: 機械的構造部品のみを含む。
  - **グリッパーコンプリートキット**: グリッパー用のモーター、配線ハーネス、構造部品を含む。
  - **フルキット**: ロボットアーム本体とグリッパーの完全なセットを含む。
  - **組立済みロボットアーム**: 完全に組み立てられた完成品のロボットアーム。

# 📊 部品表 (BOM)

> [!WARNING]
> 宣言: 公開されているBOMは、Seeedからの最終出荷バージョンを**示すものではありません**。このオープンソースv1.1は、開発者が最小コストで再現できるように最適化されており、一部の必須でない詳細は簡略化されています。
> Seeedの最終生産バージョンには、誤動作防止のための金属レーザー刻印、耐久性のために一部の3Dプリント部品を金属に置き換え、工場でのばらつきに対応するためのクリアランスと加工公差の調整（精度とコストのバランス）、および追加コストでのカスタム配線（例：組み紐スリーブ保護）が含まれます。ただし、機械的構造は同一です。

---

## 🖨️ 3Dプリント部品

| 部品説明 | 画像 | ファイル名 | 材料 | 数量 | 注記 |
|---|---|---|---|---|---|
| ロボットアームベースプラットフォーム |  | 01_BASE_Plate.step | Bambu ABS Black | 1 | 0.4mmノズル、0.2mmレイヤー高さ、30%インフィル |
| ロボットアームベースリンク |  | 01_BASE_Link.step | Bambu ABS Black | 1 | 0.4mmノズル、0.2mmレイヤー高さ、30%インフィル |
| 上アーム左フィラー |  | 01_Upper_Arm_Fuller_L.step | Bambu PLA Black & Green | 1 | 0.4mmノズル、0.2mmレイヤー高さ、15%インフィル |
| 上アーム右フィラー |  | 01_Upper_Arm_Fuller_R.step | Bambu PLA Black & Green | 1 | 0.4mmノズル、0.2mmレイヤー高さ、15%インフィル |
| 上アーム中央フィラー |  | 01_Upper_Arm_Fuller_M.step | Bambu ABS Black | 1 | 0.4mmノズル、0.2mmレイヤー高さ、30%インフィル |
| 上アーム水平リミットブロック |  | 01_Upper_Arm_Limit.step | Bambu ABS Black | 1 | 0.4mmノズル、0.2mmレイヤー高さ、30%インフィル |
| アームハンドル |  | 01_Arm_Handle.step | Bambu ABS Black | 1 | 0.4mmノズル、0.2mmレイヤー高さ、30%インフィル |
| 下アーム左フィラー |  | 01_Lower_Arm_Filler_L.step | Bambu PLA Black & Green | 1 | 0.4mmノズル、0.2mmレイヤー高さ、15%インフィル |
| 下アーム右フィラー |  | 01_Lower_Arm_Filler_R.step | Bambu PLA Black & Green | 1 | 0.4mmノズル、0.2mmレイヤー高さ、15%インフィル |
| 下アーム中央フィラー |  | 01_Lower_Arm_Filler_M.step | Bambu ABS Black | 1 | 0.4mmノズル、0.2mmレイヤー高さ、30%インフィル |
| 上アームカバー |  | 01_Upper_Arm_Cover.step | Bambu PLA Green | 1 | 0.4mmノズル、0.2mmレイヤー高さ、15%インフィル |
| 下アームカバー |  | 01_Lower_Arm_Cover.step | Bambu PLA Green | 1 | 0.4mmノズル、0.2mmレイヤー高さ、15%インフィル |
| モーター5保護カバー |  | 01_Motor_Cover.step | Bambu ABS Black | 1 | 0.4mmノズル、0.2mmレイヤー高さ、30%インフィル |
| グリッパー水平リミット |  | 01_Lower_Arm_Limit.step | Bambu PLA Green | 1 | 0.4mmノズル、0.2mmレイヤー高さ、15%インフィル |
| グリッパースライダーサポートブラケット |  | 01-Rail-Bracket.step | Bambu PLA Green | 1 | 0.4mmノズル、0.2mmレイヤー高さ、15%インフィル |
| グリッパーフィンガー |  | 01_Finger.step | Bambu ABS Black | 2 | 0.4mmノズル、0.2mmレイヤー高さ、45%インフィル |
| モーター5 ケーブル拘束 |  | 01_Joint5_Cable Restraint_A.step | Bambu PLA Green | 1 | 0.4mmノズル、0.2mmレイヤー高さ、15%インフィル |
| モーター6＆7 ケーブル拘束 A |  | 01_Joint6_7_Cable Restraint_A.step | Bambu ABS Black | 2 | 0.4mmノズル、0.2mmレイヤー高さ、30%インフィル |
| モーター6＆7 ケーブル拘束 B |  | 01_Joint6_7_Cable Restraint_B.step | Bambu ABS Black | 2 | 0.4mmノズル、0.2mmレイヤー高さ、30%インフィル |
| - | 参考価格 | 平均 **50$** | | | 材料費と印刷時間により価格変動 |

配線ハーネス1を長期間引き回して使用すると、モーター側コネクタが摩耗し、接触不良が発生する可能性があります。
下記の部品を3Dプリンタで造形することで、この不具合リスクを抑えられます。

| 部品詳細 | 画像 | ファイル名 | 材質 | 個数 | 備考 |
| ---- | ---- | ---- | ---- | ---- | ---- |
| 1号モーター両面用配線ハーネスクリップ |  | `DM_Motor1_wiring_harness_clip.stp` | Bambu Lab 黒ABS樹脂 | 2個 | ノズル径0.4mm、積層ピッチ0.2mm、充填率30% |

## 📷 対応カメラマウント

| 部品説明 | 画像 | ファイル名 | 材料 | 数量 | 注記 |
|---|---|---|---|---|---|
| [Orbbec Gemini2](https://www.seeedstudio.com/Orbbec-Gemini-2-3D-Camera-p-6464.html) |  | Gemini2_mount.step | Bambu ABS Black | 1 | 0.4mmノズル、0.2mmレイヤー高さ、30%インフィル |

### 🧩 印刷推奨事項
- レイヤー高さ: 0.2 mm
- ノズル: 0.4 mm
- サポート: 必要に応じて追加
- 材料: 高温・耐荷重部品にはABS（インフィル30～80%）、ナイロンまたはカーボン繊維強化材料も可。外装部品にはPLA（インフィル15%）。
- 耐荷重部品の推奨材料：

---

## 🔩 CNC加工金属部品

> [!WARNING]
> 注記に記載されている一部の部品は3Dプリントに置き換え可能で、コストを大幅に削減できます。

| 部品説明 | 画像 | ファイル名 | 材料 | 数量 | 加工 | 注記 |
|---|---|---|---|---|---|---|
| モーター1 ベアリングマウント |  | 02_Base_Reinforcement_Part.step | アルミニウム合金 5052 | 1 | CNC | コスト削減のため、高インフィルABSで3Dプリント可能 |
| モーター1 回転軸 |  | 02_Arm_Yaw_Limit.step | アルミニウム合金 5052 | 1 | CNC | ヨー角運動制限を追加 |
| モーター2–5 フロントスペーサー |  | 02_Motor_Front_Spacer.step | アルミニウム合金 5052 | 4 | CNC | ABS、インフィル30%で3Dプリント可能 |
| モーター2–4 リアスペーサー |  | 02_Motor_Back_Spacer.step | アルミニウム合金 5052 | 3 | CNC | |
| モーター2–4 リアフランジ |  | 02_FLANGE.step | アルミニウム合金 5052 | 3 | CNC | |
| 手首モーター5 ブラケット |  | 02_Wrist_Bracket.step | アルミニウム合金 5052 | 1 | CNC | |
| グリッパーコネクタ A |  | 02_Gripper_Connector_A.step | アルミニウム合金 5052 | 1 | CNC | |
| グリッパーコネクタ B |  | 02_Gripper_Connector_B.step | アルミニウム合金 5052 | 1 | CNC | |
| グリッパースライダー金属ブラケット |  | 02_Slider_Bracket.step | アルミニウム合金 5052 | 1 | CNC | 高インフィルABSで3Dプリント可能だが、長期使用は非推奨 |
| スライダーからグリッパーへの延長部 |  | 02_Slider_Extension.step | アルミニウム合金 5052 | 2 | CNC | |
| 上下アームリンク左 |  | 02_Lower_Upper_Link_L.step | アルミニウム合金 5052 | 1 | CNC | |
| 上下アームリンク右 |  | 02_Lower_Upper_Link_R.step | アルミニウム合金 5052 | 1 | CNC | |
| 下アーム-手首リンク左 |  | 02_Lower_Wrist_Link_L.step | アルミニウム合金 5052 | 1 | CNC | |
| 下アーム-手首リンク右 |  | 02_Lower_Wrist_Link_R.step | アルミニウム合金 5052 | 1 | CNC | |
| ギアコネクタ |  | 02_Gear_Connector.step | アルミニウム合金 5052 | 1 | CNC | |
| ラック |  | 02_Rack.step | アルミニウム合金 5052 | 2 | CNC | |
| リンク 1 |  | 03_Link1.step | アルミニウム合金 5052 | 1 | CNC + 板金 | |
| リンク 2 |  | 03_Link2.step | アルミニウム合金 5052 | 2 | CNC + 板金 | |
| リンク 3 左 |  | 03_Link3_L.step | アルミニウム合金 5052 | 1 | CNC + 板金 | |
| リンク 3 右 |  | 03_Link3_R.step | アルミニウム合金 5052 | 1 | CNC + 板金 | |
| リンク 5 |  | 03_Link5.step | アルミニウム合金 5052 | 1 | CNC + 板金 | |
| - | 市場参考価格 | 平均 **250$** | | | アルミニウムコスト、公差要件、納期により価格変動 |

### 🧩 加工仕様
- 主要寸法公差: ±0.02 mm GB/T1840-M
- 表面仕上げ: アルマイト / サンドブラスト
- 嵌合部品推奨: H7 / インターフェリンスフィット
---

## 🛒 購入部品 (標準部品)

> [!WARNING]
> 組み立て・ネジ締めはご自身で行っていただく必要があるため、標準的な六角穴付きネジを選択しています。長時間の動作後、ネジが緩み、ロボットアームの精度に影響を与える可能性があります。そのため、各ジョイントのネジにネジロックを行うためのホットメルト接着剤を別途購入する必要があります。

電動ドリルなどの工具をお持ちの場合は、代わりにロックワッシャーやネジロック剤付きネジを購入しても構いません。ただし、電動ドライバーを使用する際は**非常に重要なこと**ですが、ネジ山をなめないように最も低いトルク設定を使用してください。ネジ山をなめると、元に戻せない損傷が発生します。

| 名前 | 仕様 / モデル | 数量 | 参考価格 | 注記 |
|---|---|---|---|---|
| ブラシレスモーター | DM4310(V4) | 4 | 120 $/unit | [SeeedStudio](https://www.seeedstudio.com/DIP-Servo-Motor-24V-120RPM-Brushless-98-9mm-4P-L56-W56-H46mm-p-6660.html) |
| ブラシレスモーター | DM4340P(V4) | 3 | 175 $/unit | [SeeedStudio](https://www.seeedstudio.com/DM4340P-Actuator-p-6663.html) |
| CAN-USBドライバーボード | | 1 | 15 $/unit | [SeeedStudio](https://www.seeedstudio.com/DM-CAN-USB-Driver-Borad-p-6706.html) |
| ベアリング | 6707ZZ | 1 | 13 $/unit | [Amazon](https://www.amazon.com/uxcell-35x44x5mm-Shielded-Precision-Lubricated/dp/B0D6WBMW3F/ref=sr_1_1) |
| ベアリング | 6803ZZ | 3 | 13 $/unit | [Amazon](https://www.amazon.com/uxcell-17x26x5mm-Shielded-Precision-Lubricated/dp/B0D54JSWBZ/ref=sr_1_1) |
| ベアリング | AXK5578 | 1 | 12 $/unit | [Amazon](https://www.amazon.com/PZRT-AXK5578-Thrust-Bearings-Washers/dp/B0B3M3RZGW/ref=sr_1_1) |
| リニアレール | MGN9-170mm | 1 | 23 $/unit | [Amazon](https://www.amazon.com/uxcell-Sliding-Carriage-Bearing-Printers/dp/B0D54L45WM/ref=sr_1_1) |
| スライダーブロック | MGN9 | 2 | 10 $/unit | [Amazon](https://www.amazon.com/uxcell-Bearing-Sliding-Carriage-Anti-Fall/dp/B0D9QBQDKB/ref=sr_1_8) |
| ギア | モジュール1、ボス型、16歯、ボア6mm | 1 | 44$/unit | [Amazon](https://www.amazon.com/Module-15-Teeth-Finished-Perforation/dp/B0GDSR1LKM/ref=sr_1_1) |
| シリコンパッド | 30x9x2mm | 1 | 10 $ | [Amazon](https://www.amazon.com/Self-Adhesive-Anti-Sliding-Anti-Scratch-Protectors-Appliances/dp/B0F9KVYXFZ/ref=sr_1_3) |
| ネジ | HM3-12mm ネジ | 14+ | | [Amazon](https://www.amazon.com/BNUOK-120pcs-Stainless-Threads-Spanner/dp/B0DJQGMQZM/ref=sr_1_4) |
| ネジ | HM3-25mm ネジ | 14+ | | [Amazon](https://www.amazon.com/BNUOK-120pcs-Stainless-Threads-Spanner/dp/B0DJQFGRPQ/ref=sr_1_4) |
| ネジ | HM3-6mm ネジ | 16+ | | [Amazon](https://www.amazon.com/BNUOK-120pcs-Stainless-Threads-Spanner/dp/B0DJQG5YLF/ref=sr_1_4) |
| ネジ | HM4-75mm 止めネジ | 4+ | | [Amazon](https://www.amazon.com/iexcell-Partially-Threaded-Thread-Socket/dp/B0DR1NX178/ref=sr_1_1) |
| ネジ | KM3*12mm ネジ | 30+ | | [Amazon](https://www.amazon.com/Uxcell-a16011300ux0872-M3x12mm-Carbon-Countersunk/dp/B01E6EIC2S/ref=sr_1_1) |
| ネジ | KM3*16mm ネジ | 34+ | | [Amazon](https://www.amazon.com/Uxcell-a16011300ux0872-M3x12mm-Carbon-Countersunk/dp/B01E6EIC2S/ref=sr_1_1) |
| ネジ | KM3*7mm ネジ | 76+ | | [Amazon](https://www.amazon.com/Uxcell-a16011300ux0872-M3x12mm-Carbon-Countersunk/dp/B01E6EIC2S/ref=sr_1_1) |
| ネジ | KM3*9mm ネジ | 31+ | | [Amazon](https://www.amazon.com/Uxcell-a16011300ux0872-M3x12mm-Carbon-Countersunk/dp/B01E6EIC2S/ref=sr_1_1) |
| ネジ | KM3*8mm マイクロプロファイル六角穴付きネジ | 31+ | | [Amazon](https://www.amazon.com/SMALLRIG-Screw-Screws-12pcs-Pack/dp/B01MS60KSY/ref=sr_1_1) |
| ネジ | KA3*12mm | 72+ | | [Amazon](https://www.amazon.com/uxcell-Phillips-Tapping-Screws-Silver/dp/B01MXSS95N/ref=sr_1_3) |
| 位置決めピン | M4*8mm | 数本 | | [Amazon](https://www.amazon.com/HARFINGTON-Stainless-Cylindrical-Furniture-Installation/dp/B0F6CWL4MP/ref=sr_1_6) |
| 位置決めピン | M4*12mm | 数本 | | [Amazon](https://www.amazon.com/HARFINGTON-Stainless-Cylindrical-Furniture-Installation/dp/B0F6CWL4MP/ref=sr_1_6) |
| ドライバーセット | 六角レンチセット | 1 | 16$ | [Amazon](https://www.amazon.com/Amazon-Basics-Ratcheting-Electronics-Screwdriver/dp/B07V4TFWFZ/ref=sr_1_2) |
|  | XT30 2+2 350mm | 2 | 4 $/cable | 両端アングル |
|  | XT30 2+2 350mm | 1 | 4 $/cable | 一端アングル、一端ストレート |
|  | XT30 2+2 200mm | 3 | 4 $/cable | 両端アングル |
|  | XT30 2+2 200mm | 1 | 3 $/cable | 両端ストレート |

### 固定方法について
付属の3Dプリント部品を基に、土台を自由に加工していただけます。机の天板の厚さに合わせて、Gクランプを使用することも可能です。

| 名称 | 仕様/型式 | 数量 | 参考価格 | 備考 |
|---|---|---|---|---|
| 木工用クランプ | 6インチ Gクランプ | 2個 | 1個あたり20ドル | [Amazon](https://www.amazon.com/gp/aw/d/B092J1YW2M/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) |

### 電源について
本ロボットアームは標準で電源が付属しておりません。お手持ちのバッテリーを接続するか、台湾製の信頼性の高い**24V 14.6A MeanWell製電源**を別途ご購入ください。
加えて、現地基準に適合した3ピンプラグ、及びXT30メスコネクタ付き配線ハーネスもご用意いただく必要があります。

| 名称 | 仕様/型式 | 数量 | 参考価格 | 備考 |
|---|---|---|---|---|
| 電源装置 | 24V 14.6A | 1個 | 30ドル | [Amazon](https://www.amazon.com/MEAN-WELL-LRS-350-24-350-4W-Switchable/dp/B013ETVO12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) |
| 電源ケーブル | 12AWG | 1本 | 30ドル | [Amazon](https://www.amazon.com/Pinfox-Universal-Appliance-Replacement-Pigtail/dp/B0F5PW5SJG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) |
| 電源ケーブル | XT30 16AWG | 1本 | 9ドル | [Amazon](https://www.amazon.com/RioRand-Connector-Pigtail-Silicone-Aircraft/dp/B0FY2ZCR83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) |

---

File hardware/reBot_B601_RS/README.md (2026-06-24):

Coming Soon!
### About Power Supply
The robotic arm is shipped without a power supply by default. You may connect your own battery, or purchase a reliable 48V 12.5A MeanWell power supply made in Taiwan. Additionally, you will need to buy a three-pin plug compliant with local standards and a wiring harness with XT30 female connector.

#### Consumables BOM

| Name | Specification | Qty | Reference Price | Notes | Image |
|:---|:---|:---:|:---:|:---|:---:|
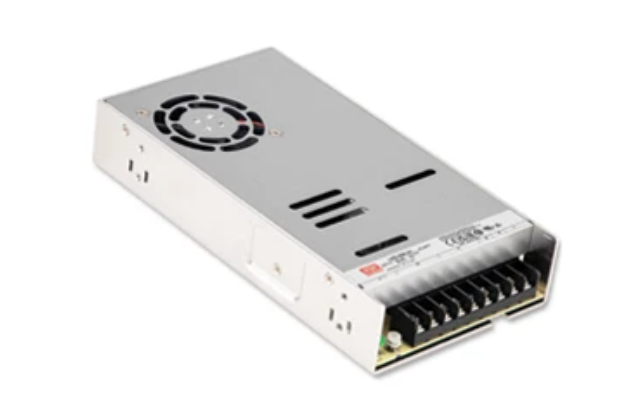
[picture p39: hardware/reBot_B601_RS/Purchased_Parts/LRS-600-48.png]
| Power Supply | LRS-600-48（48V12.5A） | 1 | $69.5 | [amazon](https://www.amazon.com/LRS-600-48-Switching-Upgrade-Version-SE-600-48/dp/B0BV5XFYNS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) |  |
| Power Cord | US Standard AC Cable | 1 | $4.49 | [amazon](https://www.amazon.com/LIFEPOE-Power-3-3ft-Black-3-Prong/dp/B0FK4KPW2G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) |  |
| Output Port | XT60E Fixed Female Connector; XT60E Female + Lug - 10cm; 4mm Lug Hole | 1 | $9.99 | [amazon](https://www.amazon.com/LINSYRC-XT60E-F-Connector-Battery-Quadcopter/dp/B0CQK1P1DP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) |  |
| Power AC Wiring | 1.5mm²; Red, Blue, Yellow x1 each(User must crimp terminals to the wire — pre-crimped leads not included.); 10CM | 3 | $0.99 | [aliexpress](https://www.aliexpress.com/item/1005008648016252.html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) |  |
| 3-in-1 IEC Inlet Socket | Quick-connect type with red switch (Dual Nuts) | 1 | $1.98 | [aliexpress](https://www.aliexpress.com/item/1005005962021242.html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) |  |
| XT30 to XT60 adapter cable plug 12awg | XT30U female to XT60 male, cable length 50cm | 1 | 9.98$ | [amazon](https://www.amazon.com/MEIRIYFA-Extension-Female-Adapter-Silicone/dp/B0B3DMJVV8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) |  |
| 304 Stainless Steel Phillips Countersunk Head Screw | M4x6 | 10 | $0.37 | / | / |
| 304 Stainless Steel Phillips Countersunk Head Screw | M3x8 | 2 | $0.36 | / | / |
| 304 Stainless Steel Phillips Pan Head Screw | M3x8 | 2 | $0.32 | / | / |
| Hex Nut | M3x2.5 | 2 | 2.10 CNY | / | / |

Printed Parts BOM:

| Name | Image | Quantity | Notes |
| --- | ---- | --- | ---- |
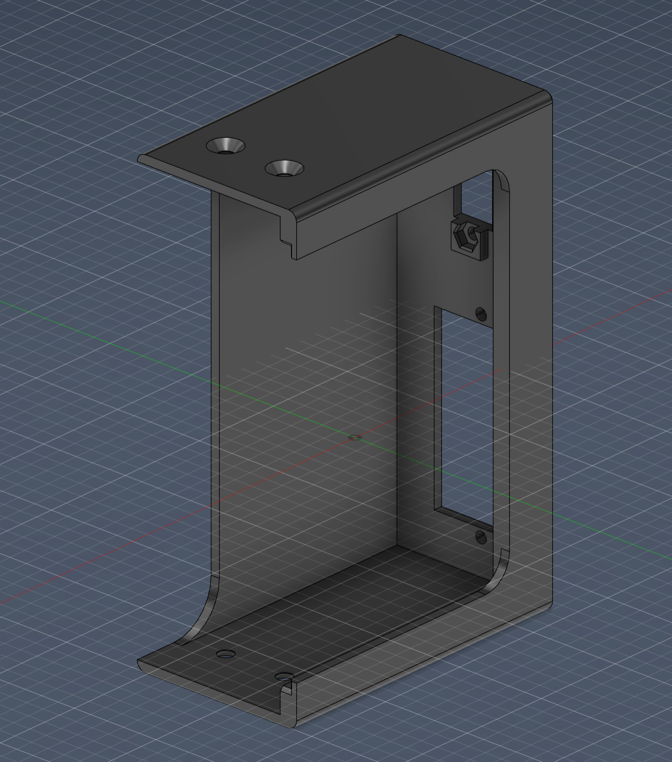
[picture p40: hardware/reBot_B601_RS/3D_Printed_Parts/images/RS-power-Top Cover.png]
| [Front Shell](./3D_Printed_Parts/RS-power-Top%20Cover.stp) |  | 1 | PLA 0.4 nozzle, 0.2 layer height, 30% infill |
| [Rear Shell](./3D_Printed_Parts/RS-power-Bottom%20Cover.stp) |  | 1 | PLA 0.4 nozzle, 0.2 layer height, 30% infill |
| [Front Shell (Sliding Cover)](./3D_Printed_Parts/RS-power-Top%20Cover-Sliding%20Cover.stp) |  | 1 | PLA 0.4 nozzle, 0.2 layer height, 30% infill |

#### Power Supply Assembly

- The power supply assembly steps are divided into two parts: front shell and rear shell:

> ⚠️ **About the photos below**: The power supply assembly photos (`Assembly_Steps/powerstep_images/`, ~42MB) are too large and are **not uploaded to GitHub by this fork**, so they will appear missing when browsing this page online.
> - They are kept in the local clone and can be viewed normally.
> - To view online, please refer to the corresponding directory in the official upstream repository [Seeed-Projects/reBot-DevArm](https://github.com/Seeed-Projects/reBot-DevArm).

##### 1. Front Shell Assembly

| Step | Description | Image | Notes |
|:---:|---|---|---|
| 1-1 | Prepare the parts and printed components required for front shell assembly |  | Check that all parts are present |
| 1-2 | Wiring sequence instructions for each part; assemble according to the wiring sequence | <br> | Connect strictly according to the wiring sequence |
| 1-3 | Install the XT60 connector |  | Secure with M3x8 304 countersunk cross-head screws and M3x2.5 hex nuts |
| 1-4 | Install the 3-in-1 IEC socket |  | Secure the 3-in-1 IEC socket with M3x8 304 pan head cross-head screws |
| 1-5 | Internal wiring of the front shell | <br> | Check connections against the wiring diagram |
| 1-6 | Secure the front shell to both sides of the power supply |  | 4x M4x6 304 countersunk cross-head screws |
| 1-7 | Install the sliding cover |  | Push in from the bottom of the power supply |
| 1-8 | Secure the sliding cover |  | 2x M4x6 304 countersunk cross-head screws |

---

##### 2. Rear Shell Assembly

| Step | Description | Image | Notes |
|:---:|---|---|---|
| 2-1 | Prepare the parts and printed components required for rear shell assembly |  | Check that all accessories are complete |
| 2-2 | Assemble the rear shell with the power supply |  | Align the position |
| 2-3 | Secure the rear shell to both sides of the power supply |  | 4x M4x6 304 countersunk cross-head screws |

---

##### 3. Final Completion

| Step | Description | Image | Notes |
|:---:|---|---|---|
| 1 | Power supply assembly completed |  | Check that all screws are tightened |

---

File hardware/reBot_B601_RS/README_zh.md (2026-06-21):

正在路上

### 关于电源

 机械臂在发货时并未配备电源/默认情况下不带电源。您可自行连接电池，或选购一款48V 12.5A AMeanWell电源供应器。此外，您还需购买符合当地标准的三芯插头以及带有XT30母接头的接线束线带。

耗材BOM：

| 名称 | 规格型号 | 数量 | 参考价格 | 备注 | 图片 |
|---|---|---|---|---|-----|
| 电源 | LRS-600-48（48V12.5A）| 1 | 240元 | [京东](https://item.jd.com/10161209537223.html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) |  |
| 电源线 | 品字头中国标AC线；1.5m-国标3*1.5平方 | 1 | 10.1元 | [淘宝](https://item.taobao.com/item.htm?id=563831183799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) |  |
| 输出口 | XT60E固定母头；XT60E固定母头+铜鼻-10厘米；4mm铜鼻孔 | 1 | 12.88元 | [淘宝](https://item.taobao.com/item.htm?id=956673114150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) |  |
| 电源AC连接线 | 1.5平方；红色，蓝色，黄注绿色各1根；UT-4.2单头半剥；10CM | 3 | 1.92元 | [淘宝](https://item.taobao.com/item.htm?id=735823838383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) |  |
| 三合一品字插座 | 带红开快接款(双螺帽)（红灯） | 1 | 6.6元 | [淘宝](https://detail.tmall.com/item.htm?id=970232786169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) |  |
| XT30转XT60连接线插头线航模16awg | XT30U母头转XT60公头 线长30CM | 1 | 7.5元 | [淘宝](https://item.taobao.com/item.htm?id=933046470955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) |  |
| 304十字沉头螺丝 | M4X6 | 10 | 2.39元 | / | / |
| 304十字沉头螺丝 | M3X8 | 2 | 2.34元 | / | / |
| 304十字圆头螺丝 | M3X8 | 2 | 2.1元 | / | / |
| 六角螺母 | M3X2.5 | 2 | 2.1元 | / | / |

打印件BOM：

| 名称 | 图片 | 数量  | 备注  |
| --- | ---- | --- | ---- |
| [前壳](./3D_Printed_Parts/RS-power-Top%20Cover.stp) |  | 1 | PLA0.4喷嘴 0.2层高 30%填充 |
| [后壳](./3D_Printed_Parts/RS-power-Bottom%20Cover.stp) |  | 1 | PLA0.4喷嘴 0.2层高 30%填充 |
| [前壳（滑盖）](./3D_Printed_Parts/RS-power-Top%20Cover-Sliding%20Cover.stp) |  | 1 | PLA0.4喷嘴 0.2层高 30%填充 |

#### 电源组装

- 电源方案组装步骤分为前壳和后壳两个部分：

> ⚠️ **关于下方实拍图**：电源组装实拍图（`Assembly_Steps/powerstep_images/`，约 42MB）体积过大，**本 fork 未上传到 GitHub**，因此在线浏览本页时下方表格的实拍图会显示为缺失。
> - 本地 clone 中这些图已保留，可正常查看。
> - 在线查看请移步官方上游仓库 [Seeed-Projects/reBot-DevArm](https://github.com/Seeed-Projects/reBot-DevArm) 的对应目录。

##### 1.前壳组装

| Step | 操作说明 | 图片 | 备注 |
|:---:|---|---|---|
| 1-1 | 准备前壳组装所需零件和打印件 |  | 检查零件是否齐全 |
| 1-2 | 各零件线序说明，按线序进行组装 | <br> | 严格按照线序连接 |
| 1-3 | 安装 XT60 座子 |  | 使用304十字沉头螺丝M3X8和六角螺母M3X2.5固定 |
| 1-4 | 安装三合一品字插座 |  | 304十字圆头螺丝M3X8对三合一品字插座固定 |
| 1-5 | 前壳内部接线 | <br> | 对照线序图检查连接 |
| 1-6 | 固定前壳与电源两侧 |  | M4X6_304十字沉头螺丝X4 |
| 1-7 | 安装滑盖 |  | 从电源底部推入 |
| 1-8 | 固定滑盖 |  | M4X6_304十字沉头螺丝X2 |

---

##### 2.后壳组装

| Step | 操作说明 | 图片 | 备注 |
|:---:|---|---|---|
| 2-1 | 准备后壳组装所需零件和打印件 |  | 检查配件完整性 |
| 2-2 | 将后壳与电源组装 |  | 对齐位置 |
| 2-3 | 固定后壳与电源两侧 |  | M4X6_304十字沉头螺丝X4 |

---

##### 3.总体完成

| Step | 操作说明 | 图片 | 备注 |
|:---:|---|---|---|
| 1 | 电源方案总体组装完成 |  | 检查所有螺丝紧固情况 |

---

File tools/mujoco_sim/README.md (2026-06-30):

# reBot MuJoCo 物理仿真（外部 MuJoCo + rosbridge）

物理仿真第 4 件。**核心思路：让 MuJoCo 在 ROS 上「装成另一台 reBot 机器人」**——发和真机同名的
`/rebotarm/joint_states`、收同样的 `/rebotarm/joints/<j>/cmd/pos_vel`。这样网页驾驶舱（经 rosbridge）
的镜像/命令链路**一行不用改**：网页分不清关节状态来自真臂还是 MuJoCo。中间桥 = 你已经在用的 rosbridge。

```
浏览器 cockpit ──(rosbridge ws://:9090)── /rebotarm/joint_states ◄── MuJoCo 物理(本节点)
   ▲ 3D 跟随(镜像)                          /rebotarm/joints/*/cmd/pos_vel ──► MuJoCo ctrl
   └ 发命令 ───────────────────────────────────────────────────────────────────┘
```

## 跑在哪
装了 **ROS2 + mujoco + 编了 `rebotarm_msgs`(含 JointPosVelCmd)** 的机器（机器人机 / WSL）。
**不在网页那台跑物理**——网页只是经 rosbridge 看/控这台。

## 一次性准备
```bash
pip install mujoco                              # 物理引擎(python)
sudo apt install ros-$ROS_DISTRO-rosbridge-suite   # 网页靠 rosbridge 连进来（如没装）
# 确保 rebotarm_msgs 已编：在你的 ROS2 工作区 colcon build 后 source install/setup.bash
```

## 步骤
1. **生成物理模型**（用 mujoco 自己的 URDF 导入器转，再加执行器/阻尼/地面）：
   ```bash
   cd tools/mujoco_sim
   python urdf_to_mjcf.py \
     --urdf  ../../software/reBotArmController_ROS2/src/rebotarm_bringup/description/urdf/reBot-DevArm_fixend.urdf \
     --meshes ../../software/reBotArmController_ROS2/src/rebotarm_bringup/description/meshes \
     --out reBot_scene.xml
   ```
2. **先自检/桌面验证再上 ROS**（最值的一步：模型/物理/控制问题在这全暴露，已在开发机 Windows 上跑通）：
   ```bash
   python selfcheck.py reBot_scene.xml      # 一键自检(不需 ROS)：加载/关节解析/物理不发散/执行器能驱动关节 → 全 PASS 才往下
   python -m mujoco.viewer reBot_scene.xml   # 有桌面的话再肉眼看一眼(可选)
   ```
   - selfcheck 全 PASS = 模型+物理+控制逻辑没问题。有 [FAIL] 把那行贴出来。
   - viewer 里：臂应**站住**（执行器托得住自重、不软趴不抖）。软趴=调大 `urdf_to_mjcf.py` 顶部 `KP`；抖/迟钝=调 `KV`/`DAMP`/`ARMATURE`。
   - **注意**：MVP 已**关闭接触**（`<flag contact="disable">`），因为 URDF 全分辨率碰撞网格相邻连杆会自碰把臂"焊死"。所以现在臂**穿过自己/地面不挡**是正常的；以后做抓取再开接触 + 加相邻连杆 `<contact><exclude>`。
3. **起 rosbridge**（另一个终端，网页靠它连进来）：
   ```bash
   ros2 launch rosbridge_server rosbridge_websocket_launch.xml
   ```
4. **起仿真节点**：
   ```bash
   ROS_SETUP=~/你的ws/install/setup.bash bash run_mujoco_sim.sh
   #   想同时开本地 MuJoCo 窗口看： MUJOCO_VIEWER=1 ROS_SETUP=... bash run_mujoco_sim.sh
   #   mujoco 在 venv/conda 里： 再加 SIM_VENV=/path/venv 或 SIM_CONDA_ENV=名字
   ```
5. **网页连上**：浏览器开 cockpit → ROS 面板 WebSocket 填 `ws://<这台IP>:9090` → 连接 →
   顶栏开 **「跟随」** → MuJoCo 的关节实时映射进 3D。要让网页驱动仿真：勾「允许网页发控制」+ 模式选
   `仿真驱动 (fake)` 或直接发滑块/IK → 命令经 `cmd/pos_vel` 进 MuJoCo，物理算完再 joint_states 回来。

## MVP 范围（这版有/没有）
- ✅ 关节镜像（MuJoCo→3D）、6 轴 `cmd/pos_vel` 驱动（网页→MuJoCo）、重力下的真实下垂/超调。
- ❌ 夹爪（reBot URDF 里没有夹爪关节，物理模型暂无；网页夹爪按钮对仿真无效）。
- ❌ enable/disable / 重力补偿 / IK / move_to_pose 等**服务**——那些是真控制器的，仿真没起这些 service，
  网页点了会报「服务不存在」，**属正常**（仿真只实现 joint_states + pos_vel 这条最小链路）。
- ⚠️ 网页诊断面板里 **「臂状态」「夹爪」两格会一直红/等待**——仿真不发 `arm_status` / `gripper/state` 话题，**正常**，不影响跟随/控制。
- ⚠️ **`vlim`(限速)被忽略**：仿真里关节速度由 kp/kv/forcerange 决定，网页的 vlim 滑块对仿真无效（真机才用它限速）。

## 注意
- **别同时**把真机和这个仿真都连到同一个 `rebotarm` namespace（话题会打架）。要么连真机、要么连仿真。
- kp/阻尼/armature 是先验值，**必须在 viewer 里按手感调**（见步骤 2）。调好的值填回 `urdf_to_mjcf.py` 顶部常量重生成。
- 这套是「写好你来跑/调」：物理要在 Linux+ROS+mujoco 上才跑得起来，开发机(Windows)只出代码。

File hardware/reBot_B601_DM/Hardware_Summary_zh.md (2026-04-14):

# reBot Arm B601 DM 硬件总结文档

> 基于项目 BOM 及电机官方说明书整理，版本 v1.0 (2026.04)

---

## 1. 整机概览

| 项目 | 说明 |
|---|---|
| 产品名称 | reBot Arm B601 DM |
| 自由度 | 6+1（6轴机械臂 + 1轴夹爪） |
| 电机品牌 | 达妙科技（Damiao / DMBOTS） |
| 电机型号 | DM-J4310-2EC V1.1 × 4 + DM-J4340P-2EC × 3 |
| 通信总线 | CAN 2.0B @ 1Mbps（支持 CAN FD） |
| 供电电压 | 24V DC |
| 供电电源 | 24V / 14.6A / 350W 开关电源 |
| 推荐负载 | ≤ 1.5 kg |
| 推荐工作臂展 | < 70%（约 450mm） |
| 整机装配文件 | `reBot_B601_DM_v1.0_20260331.step` |

---

## 2. 电机参数

两款电机均为 **驱动一体化设计**（电机 + FOC驱动器 + 双编码器集成），无需外接驱动器。

### 2.1 DM-J4310-2EC V1.1（小关节电机 × 4）

| 类别 | 参数 | 数值 |
|---|---|---|
| **电气** | 额定电压 | 24V |
| | 额定电流 | 2.5A |
| | 峰值电流 | 7.5A |
| **扭矩** | 额定扭矩 | 3 Nm |
| | 峰值扭矩 | **7 Nm** |
| **转速** | 额定转速 | 120 rpm |
| | 空载最大转速 | 200 rpm |
| **减速器** | 减速比 | 10:1 |
| **电机特征** | 极对数 | 14 |
| | 相电感 | 340 μH |
| | 相电阻 | 650 mΩ |
| **结构** | 外径 × 高度 | 56mm × 46mm |
| | 重量 | ~300g |

### 2.2 DM-J4340P-2EC（大关节电机 × 3）

| 类别 | 参数 | 24V 版（本项目使用） | 48V 版 |
|---|---|---|---|
| **电气** | 额定电压 | 24V | 48V |
| | 额定电流 | 2.5A | 2.5A |
| | 峰值电流 | 8A | 8A |
| **扭矩** | 额定扭矩 | 9 Nm | 9 Nm |
| | 峰值扭矩 | **27 Nm** | **27 Nm** |
| **转速** | 额定转速 | 36 rpm | 36 rpm |
| | 空载最大转速 | 52 rpm | 100 rpm |
| **减速器** | 减速比 | 40:1 | 40:1 |
| **电机特征** | 极对数 | 14 | 14 |
| | 相电感 | 360 μH | 360 μH |
| | 相电阻 | 880 mΩ | 880 mΩ |
| | 最大电流（力位混控） | 10.26A | 10.26A |
| **结构** | 外径 × 高度 | 57mm × 56.5mm | 同左 |
| | 重量 | ~375g | ~375g |

### 2.3 两款电机对比

| 对比项 | DM-J4310 (×4) | DM-J4340P (×3) |
|---|---|---|
| 定位 | 小关节（小臂、腕部） | 大关节（底座、肩部） |
| 峰值扭矩 | 7 Nm | 27 Nm（大 3.9 倍） |
| 额定转速 | 120 rpm | 36 rpm（慢 3.3 倍） |
| 减速比 | 10:1 | 40:1（高 4 倍） |
| 控制模式 | 3 种 | 4 种（多力位混控） |
| 重量 | 300g | 375g |
| 单价 | 599 元 | 899 元 |

---

## 3. 内置驱动器参数

两款电机驱动器规格相同，4340P 多一个力位混控模式。

| 参数 | 数值 |
|---|---|
| **编码器** | 双 14 位磁编码器（16384 分辨率/圈） |
| **编码器类型** | 磁编，单圈绝对值，**掉电不丢位置** |
| **控制接口** | CAN 总线 @ 1Mbps（默认） |
| **调参接口** | UART @ 921600bps |
| **CAN 波特率可选** | 125K / 200K / 250K / 500K / 1M / 2M / 2.5M / 3.2M / 4M / 5M |
| **CAN FD** | 波特率 > 1Mbps 时自动切换为 CAN FD |

### 3.1 控制模式

| 模式 | DM-J4310 | DM-J4340P | 说明 |
|---|---|---|---|
| MIT 模式 | 支持 | 支持 | 兼容 MIT Mini Cheetah 协议，位置+速度+Kp+Kd+力矩前馈 |
| 位置速度模式 | 支持 | 支持 | 三环串级控制，梯形加减速，精度高，响应柔顺 |
| 速度模式 | 支持 | 支持 | 恒速控制，阻尼因子推荐 4.0 |
| 力位混控模式 | 不支持 | **支持** | 位置控制 + 扭矩限幅，适合柔顺控制和安全交互 |

### 3.2 保护机制

| 保护类型 | 阈值 | 动作 |
|---|---|---|
| 驱动 MOS 过温 | 120°C | 自动退出使能 |
| 电机线圈过温 | 建议 ≤ 100°C（可设定） | 自动退出使能 |
| 过压 | 24V版 ≤ 32V / 48V版 ≤ 52V | 自动退出使能 |
| 欠压 | 建议 ≥ 15V（可设定） | 自动退出使能 |
| 过流 | 建议 ≤ 9.8A（可设定） | 自动退出使能 |
| 通讯丢失 | 超时时间可设定 | 自动退出使能 |
| 过载 | 内部判定 | 自动退出使能 |

### 3.3 指示灯状态

| 状态 | 指示灯 | 说明 |
|---|---|---|
| 正常使能 | 绿灯常亮 | 正常工作 |
| 失能 | 红灯常亮 | 未使能 |
| 故障 | 红灯闪烁 | 故障码：8-超压 / 9-欠压 / A-过流 / B-MOS过温 / C-线圈过温 / D-通讯丢失 / E-过载 |

---

## 4. CAN 通信协议

### 4.1 反馈帧（所有模式通用）

| 字节 | D[0] | D[1] | D[2] | D[3] | D[4] | D[5] | D[6] | D[7] |
|---|---|---|---|---|---|---|---|---|
| 内容 | ID\|ERR<<4 | POS[15:8] | POS[7:0] | VEL[11:4] | VEL[3:0]\|T[11:8] | T[7:0] | T_MOS(°C) | T_Rotor(°C) |

- POS：16位位置（线性映射）
- VEL：12位速度（线性映射）
- T：12位扭矩（线性映射）

### 4.2 控制帧 ID 规则

| 模式 | 帧 ID | 数据内容 |
|---|---|---|
| MIT | CAN_ID | p_des(16bit) + v_des(12bit) + Kp(12bit) + Kd(12bit) + t_ff(12bit) |
| 位置速度 | 0x100 + CAN_ID | p_des(float) + v_des(float) |
| 速度 | 0x200 + CAN_ID | v_des(float) |
| 力位混控 | 0x300 + CAN_ID | p_des(float) + v_des(uint16) + i_des(uint16) |

### 4.3 参数读写命令

| 命令 | 帧 ID | D[0]-D[1] | D[2] | D[3] | D[4]-D[7] |
|---|---|---|---|---|---|
| 读寄存器 | 0x7FF | CAN_ID(L/H) | 0x33 | 寄存器地址 | - |
| 写寄存器 | 0x7FF | CAN_ID(L/H) | 0x55 | 寄存器地址 | 数据(float/uint32) |
| 存储参数 | 0x7FF | CAN_ID(L/H) | 0xAA | 0x01 | - |

> 注意：存储参数仅失能模式下生效，Flash 擦写约 1 万次寿命，勿频繁调用。

---

## 5. 供电系统

### 5.1 电源配置

| 参数 | 数值 |
|---|---|
| 电源规格 | 24V / 14.6A / **350W** 开关电源 |
| 输入 | 220V AC（三脚插头） |
| 输出接口 | XT30 母头，16号线 |
| 电源价格 | 105 元 + 10 元插头 + 32 元 XT30 线 = **147 元** |

### 5.2 功耗估算

| 工况 | 估算功耗 |
|---|---|
| 待机/失能 | ~10W |
| 轻载低速运动 | 50 - 100W |
| 正常工作（≤1.5kg） | 100 - 200W |
| 高负载快速运动 | 200 - 300W |
| 多关节同时峰值（极端） | >350W |

> 350W 电源覆盖推荐工况。如需更大余量可换 24V/20A（480W）。

### 5.3 电气连接

| 设备 | 数量 | 价格 | 用途 |
|---|---|---|---|
| CAN-USB 驱动板 | 1 | 60 元 | 电脑 USB 转 CAN 总线 |
| CAN-电源分离板 | 1 | 9 元 | CAN 信号与电源分离 |
| XT30 2+2 线束 350mm（两端弯头） | 2 | 25 元/根 | 电机串联 |
| XT30 2+2 线束 350mm（一弯一直） | 1 | 25 元/根 | 电机串联 |
| XT30 2+2 线束 200mm（两端弯头） | 3 | 22 元/根 | 电机串联 |
| XT30 2+2 线束 200mm（两端直头） | 1 | 15 元/根（需定制） | 电机串联 |

通信拓扑：
```
电脑 USB ──> CAN-USB驱动板 ──> CAN-电源分离板 ──┬── 24V电源
                                                  │
                                                  └── XT30线束菊花链串联 7 个电机
                                                      (每个电机有2个XT30口，一进一出)
```

---

## 6. 机械结构件

### 6.1 3D 打印件（17件，参考价 ~350 元）

| 零件 | 文件名 | 材料 | 数量 | 填充 |
|---|---|---|---|---|
| 底座平台 | `01_BASE_Plate.step` | ABS 黑 | 1 | 30% |
| 底座 | `01_BASE_Link.step` | ABS 黑 | 1 | 30% |
| 大臂左填充 | `01_Upper_Arm_Fuller_L.step` | PLA 黑绿 | 1 | 15% |
| 大臂右填充 | `01_Upper_Arm_Fuller_R.step` | PLA 黑绿 | 1 | 15% |
| 大臂中填充 | `01_Upper_Arm_Fuller_M.step` | ABS 黑 | 1 | 30% |
| 大臂限位块 | `01_Upper_Arm_Limit.step` | ABS 黑 | 1 | 30% |
| 提手 | `01_Arm_Handle.step` | ABS 黑 | 1 | 30% |
| 小臂左填充 | `01_Lower_Arm_Filler_L.step` | PLA 黑绿 | 1 | 15% |
| 小臂右填充 | `01_Lower_Arm_Filler_R.step` | PLA 黑绿 | 1 | 15% |
| 小臂中填充 | `01_Lower_Arm_Filler_M.step` | ABS 黑 | 1 | 30% |
| 大臂装饰盖 | `01_Upper_Arm_Cover.step` | PLA 绿 | 1 | 15% |
| 小臂装饰盖 | `01_Lower_Arm_Cover.step` | PLA 绿 | 1 | 15% |
| 电机5保护盖 | `01_Motor_Cover.step` | ABS 黑 | 1 | 30% |
| 夹爪限位 | `01_Lower_Arm_Limit.step` | PLA 绿 | 1 | 15% |
| 夹爪滑块支架 | `01-Rail-Bracket.step` | PLA 绿 | 1 | 15% |
| 夹爪手指 | `01_Finger.step` | ABS 黑 | **2** | 45% |

打印参数：0.4mm 喷嘴、0.2mm 层高、按需添加支撑。

### 6.2 CNC 金属加工件（21件，参考价 ~1500 元）

材料统一为 **铝合金 5052**，关键公差 ±0.02mm，表面阳极氧化/喷砂。

| 零件 | 文件名 | 数量 | 工艺 | 可3D打印替代 |
|---|---|---|---|---|
| 电机1轴承安装位 | `02_Base_Motor_Shim.step` | 1 | CNC | 可（ABS高填充） |
| 电机1旋转轴 | `02_Arm_Yaw_Limit.step` | 1 | CNC | 否 |
| 电机2-5正面垫片 | `02_Motor_Front_Spacer.step` | 4 | CNC | 可（ABS 30%） |
| 电机2-4背面垫片 | `02_Motor_Back_Spacer.step` | 3 | CNC | 否 |
| 电机2-4背面法兰 | `02_FLANGE.step` | 3 | CNC | 否 |
| 腕部电机5底座 | `02_Wrist_Bracket.step` | 1 | CNC | 否 |
| 爪子连接器A | `02_Gripper_Connector_A.step` | 1 | CNC | 否 |
| 爪子连接器B | `02_Gripper_Connector_B.step` | 1 | CNC | 否 |
| 爪子滑块金属支架 | `02_Slider_Bracket.step` | 1 | CNC | 可（不推荐长期） |
| 滑块爪子连接器 | `02_Slider_Extension.step` | 2 | CNC | 否 |
| 大小臂关节连接左 | `02_Lower_Upper_Link_L.step` | 1 | CNC | 否 |
| 大小臂关节连接右 | `02_Lower_Upper_Link_R.step` | 1 | CNC | 否 |
| 小臂腕关节连接左 | `02_Lower_Wrist_Link_L.step` | 1 | CNC | 否 |
| 小臂腕关节连接右 | `02_Lower_Wrist_Link_R.step` | 1 | CNC | 否 |
| 齿轮连接器 | `02_Gear_Connector.step` | 1 | CNC | 可（ABS 80%，低负载） |
| 齿条 | `02_Rack.step` | 2 | CNC | 否 |
| 连杆1 | `03-Link1.step` | 1 | CNC+钣金 | 否 |
| 连杆2 | `03-Link2.step` | 2 | CNC+钣金 | 否 |
| 连杆3左 | `03-Link3_L.step` | 1 | CNC+钣金 | 否 |
| 连杆3右 | `03-Link3_R.step` | 1 | CNC+钣金 | 否 |
| 连杆5 | `03-Link5.step` | 1 | CNC+钣金 | 否 |

### 6.3 外购标准件

| 名称 | 规格 | 数量 | 参考价格 |
|---|---|---|---|
| 轴承 | 6707ZZ (35×47×7mm) | 1 | 14.8 元 |
| 轴承 | 6803ZZ (17×26×5mm) | 3 | 1.25 元/个 |
| 推力轴承 | AXK5578 (55×78×3mm) | 1 | 17 元 |
| 滑轨 | MGN9-170mm | 1 | 20 元 |
| 滑块 | MGN9 | 2 | 20 元/个 |
| 齿轮 | 1模凸台16齿内孔5 | 1 | 4.9 元 |
| 硅胶垫 | 30×9×2mm | 1 | 4.6 元 |
| 铜柱 | M4×50mm | 4 | 10 元 |
| 螺丝 | M3×22mm 内六角 | 若干 | - |
| 螺丝 | M4×16mm 内六角 | 若干 | - |
| 螺丝 | M3×8mm 无头 | 5 | - |
| 螺丝 | M3×22mm 埋头 | 若干 | - |
| 螺丝 | M3×8mm 埋头 | 若干 | - |
| 螺丝 | M3×16mm 埋头 | 若干 | - |
| 螺丝 | M3×12mm 自攻 | 若干 | - |
| 定位销 | M4×8mm | 若干 | - |
| 定位销 | M4×12mm | 若干 | - |
| 木工夹 | 6寸G夹 | 2 | 23.8 元/个 |

> 注意：螺丝建议使用热熔胶防松。使用电动螺丝刀务必用最小档，防止滑丝。

---

## 7. 成本汇总

| 类别 | 参考价格 |
|---|---|
| DM-J4310 × 4 | 2,396 元 |
| DM-J4340P × 3 | 2,697 元 |
| 3D 打印件 | ~350 元 |
| CNC 金属件 | ~1,500 元 |
| 电源 + 线材 | ~147 元 |
| CAN-USB + 分离板 | ~69 元 |
| XT30 线束 × 7 | ~156 元 |
| 轴承 + 滑轨 + 标准件 | ~200 元 |
| 螺丝 + 工具 | ~100 元 |
| **合计（自行加工）** | **约 7,600 元** |

---

## 8. 性能测试参考

> 基于 DM V4 电机版本，V3 及更早版本性能有差异。

### 推荐工作条件

| 参数 | 推荐值 |
|---|---|
| 负载 | < 1.5 kg |
| 工作臂展 | < 70%（约 450mm） |
| 运动速度 | < 70% 最大速度 |
| 环境温度 | 15°C ~ 35°C |

### 极限测试结果

| 测试项 | 负载 | 持续时间 | 终止原因 |
|---|---|---|---|
| 5%-70% 往复运动 | 1.5 kg | > 2 h | 2号电机 90°C，人为终止 |
| 5%-70% 往复运动 | 2.5 kg | 40 min | 2号电机过热保护 |
| 5%-100% 往复运动 | 1.5 kg | 45 min | 2号电机过热保护 |
| 70% 臂展静止悬停 | 1.5 kg | 18 min | 2号电机过热保护 |
| 100% 臂展静止悬停 | 1.5 kg | 3 min | 2号电机过热保护 |

> 瓶颈在 2 号电机（肩部大关节），建议长时间工作增加主动散热，连续 2 小时后休息 10-15 分钟。

---

## 9. 资料来源与参考链接

| 资料 | 链接 |
|---|---|
| 项目仓库 | https://github.com/PeterH0323/reBot-DevArm |
| 达妙官网 | https://www.mdmbot.com/ |
| 达妙 Gitee（固件/协议/调试助手） | https://gitee.com/kit-miao/damiao |
| DM-J4310 说明书 PDF | `Motor_Datasheets/DM-J4310-2EC_V1.1_Manual.pdf` |
| DM-J4340P 说明书 PDF | `Motor_Datasheets/DM-J4340P-2EC_Manual.pdf` |
| SeeedStudio Wiki - 达妙电机 | https://wiki.seeedstudio.com/cn/damiao_series/ |
| SeeedStudio Wiki - Robstride 电机 | https://wiki.seeedstudio.com/cn/robstride_control/ |
| Discord 社区 | https://discord.gg/AbGuqJhDpQ |
| 技术支持邮箱 | yaohui.zhu@seeed.cc |

---

## 10. 当前缺失信息

| 缺失项 | 说明 |
|---|---|
| 电气接线拓扑图 | 7个电机的 CAN ID 分配、串联顺序、走线方式未说明 |
| 关节-电机对应关系 | 未标注哪个关节用 4310、哪个用 4340P |
| CAN-USB 驱动板型号 | 仅有淘宝链接，无具体型号和资料 |
| 螺丝精确数量 | BOM 中多处写"若干" |
| URDF / DH 参数 | 运动学参数未开源（软件部分待发布） |
| 组装视频 | 预计 2026.04.10 发布 |
| B601 RS 版全部资料 | 仅"Coming Soon" |

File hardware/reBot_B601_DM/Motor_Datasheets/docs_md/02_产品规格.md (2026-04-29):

# 02 产品规格

> DM-J4310-2EC V1.2 技术参数

---

## 特征参数

请根据以下参数合理使用电机。

### 电源参数

| 类型 | 特征参数 | DM-J4310-2EC V1.2 (24V) | DM-J4310-2EC V1.2 (48V) |
|---|---|---|---|
| **电源** | 额定电压 | 24V | 48V |
| | 额定相/电源电流 | 4.9A / 3.1A @ 24V | 4.8A / 1.6A @ 48V |
| | 峰值相/电源电流 | 20A / 16.5A @ 24V | 20A / 12.8A @ 48V |

### 电机参数

| 类型 | 特征参数 | 数值 |
|---|---|---|
| **性能** | 额定扭矩 | 3.5 N·m |
| | 峰值扭矩 | 12.5 N·m |
| | 额定转速 | 120 rpm |
| | 空载最大转速 (24V) | 200 rpm |
| | 空载最大转速 (48V) | 450 rpm |
| | 减速比 | 10:1 |
| | 极对数 | 14 |
| **电气特性** | 相电感 | 约 320 μH |
| | 相电阻 | 约 580 mΩ |

### 结构与重量

| 类型 | 特征参数 | 数值 |
|---|---|---|
| **尺寸** | 外径 | 57 mm |
| | 高度 | 46 mm |
| **重量** | 电机重量 | 约 325 g |

### 编码器

| 类型 | 特征参数 | 数值 |
|---|---|---|
| **编码器** | 编码器位数 | 16 位 |
| | 编码器个数 | 2 |
| | 编码器类型 | 磁编（单圈） |

### 通讯

| 类型 | 特征参数 | 数值 |
|---|---|---|
| **接口** | 控制接口 | CAN @ 1 Mbps |
| | 调参接口 | UART @ 921600 bps |

### 控制模式

- MIT 模式
- 速度模式
- 位置模式
- 力位混控模式

### 控制与保护

| 保护类型 | 说明 |
|---|---|
| **驱动过温防护** | 防护温度：120℃，过温电机将退出"使能模式" |
| **电机过温防护** | 根据使用需求设定，建议不超过 100℃，过温电机将退出"使能模式" |
| **电机过压防护** | 根据使用需求设定，建议不超过 32V，过压将退出"使能模式" |
| **通讯丢失防护** | 设定周期内没有收到 CAN 指令将自动退出"使能模式" |
| **电机过流防护** | 根据使用需求设定，建议不超过 9.8A，过流将退出"使能模式" |
| **电机欠压防护** | 若电源电压低于设定值，则退出"使能模式"，建议电源电压不低于 15V |

---

## 工作电压

### 24V 版本
- **工作电压范围**：24V - 28V
- **最低工作电压**：20V
- **最高工作电压**：28V

### 48V 版本
- **工作电压范围**：24V - 48V
- **最低工作电压**：20V
- **最高工作电压**：58V
- **注意**：超过 36V 建议减少热插拔

---

## 最大相电流

### 查询方法
可以通过上电时串口打印信息查询相应驱动器的最大相电流。

### 设置方法
可以通过调试助手进行设置运行的最大相电流百分比来进行限定：
- **默认值**：0.8（即能采样的最大电流的 80%）
- **建议值**：不要超过 98%

---

## 最高转速

最高转速由多种因素限制，包括：
- 电源电压 (V_BUS)
- 磁链值 (ψ_f)
- 减速比 (GR)

### 计算公式

```
V_MAX (rad/s) = 0.57735 × V_BUS / (N_pp × GR × ψ_f)
```

**参数说明**：
- `V_BUS`：电源电压
- `N_pp`：电机极对数
- `ψ_f`：转子磁链
- `GR`：减速比

---

## 扭矩系数

电机的扭矩系数在额定范围内可视为常数，加上减速箱之后可用如下公式进行计算：

### 计算公式

```
K_t = 1.5 × N_pp × ψ_f × GR × GREF
```

**参数说明**：
- `N_pp`：极对数
- `ψ_f`：转子磁链
- `GR`：电机减速比
- `GREF`：减速箱力矩传递系数

---

## TN 曲线

**测试条件**：
- 版本：24V 版本
- 转速：定速 120 rpm
- 环境温度：室温 25℃

**性能曲线图**：

TN曲线

---

**返回** [00_目录.md](00_目录.md)  
**上一章** [01_产品介绍.md](01_产品介绍.md)  
**下一章** [03_硬件说明.md](03_硬件说明.md)

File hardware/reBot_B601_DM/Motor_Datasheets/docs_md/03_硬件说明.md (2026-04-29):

# 03 硬件说明

> DM-J4310-2EC V1.2 硬件接口与安装

---

## 物品清单

购买电机后，包装内应包含以下物品：

1. **电机（含驱动）** × 1
2. **电源（含 CAN 通信端子）连接线**：XT30(2+2)-F 插头连接线 × 1
3. **调试串口信号线**：GH1.25 连接线-3pin × 1

---

## 接口及线序说明

### 接口总览

| 接口名称 | 接口标注 | 说明 |
|---|---|---|
| **电源接口-1** | XT30(2+2)-F | 1. 通过 XT30(2+2)-F 插头的电源连接线连接电源，额定电压为 24V，为电机供电<br>2. 通过 CAN 通信端子连接外部控制设备，可接收 CAN 控制命令，反馈电机状态信息 |
| **电源接口-2** | XT30(2+2)-F | 3. 电机包含两个电源接口，任一接口可单独连接使用，也可多机串联使用，方便走线 |
| **调试串口-3** | GH1.25-3pin | 通过 GH1.25 连接线-3pin，使用 USB 转 CAN 调试工具（或使用通用 USB 转串口模块）连接到 PC，通过达妙科技调试助手对电机进行参数设置，以及固件升级等 |

### 接口详细说明

#### 电源接口（XT30 2+2）

**功能**：
1. 电源供电（24V 或 48V）
2. CAN 通信（CAN_H、CAN_L）

**特点**：
- 电机有两个相同的电源接口
- 可单独使用一个接口
- 可串联多个电机，方便走线

#### 调试串口（GH1.25-3pin）

**功能**：
1. 参数读写
2. 固件升级
3. 电机校准

**连接方式**：
- 使用 USB 转串口模块连接到 PC
- 波特率：921600 bps

---

## 电机尺寸及安装

### 尺寸参数

| 参数 | 数值 |
|---|---|
| **外径** | 57 mm |
| **高度** | 46 mm |
| **重量** | 约 325 g |

### 安装尺寸图

电机尺寸图

**安装要点**：
1. 确保电机安装正确、稳固
2. 避免杂物进入转子内部
3. 预留足够的散热空间

---

## 指示灯状态

电机驱动板上有指示灯，用于显示电机当前状态。

### 指示灯说明

| 灯色 | 状态 | 说明 |
|---|---|---|
| **红灯常亮** | 失能状态 | 电机未使能，不接受控制命令 |
| **绿灯常亮** | 使能状态 | 电机已使能，可以接受控制命令 |
| **红灯闪烁** | 错误状态 | 电机出现错误，需要排查故障 |

### 错误类型（红灯闪烁）

当红灯闪烁时，可通过以下方式查看具体错误类型：
1. 串口打印信息
2. CAN 反馈帧中的错误代码
3. 调试助手显示的错误信息

**常见错误**：
- 过温保护
- 过压保护
- 欠压保护
- 过流保护
- 通讯丢失
- 编码器校准失败（错误类型 3）

---

## 接线注意事项

### 电源接线
1. **确认电压等级**：24V 版本使用 24V 电源，48V 版本使用 48V 电源
2. **注意极性**：正负极不可接反
3. **电源容量**：确保电源能提供足够的电流（峰值电流 24V 版本 16.5A，48V 版本 12.8A）

### CAN 接线
1. **CAN_H 和 CAN_L**：注意不要接反
2. **终端电阻**：CAN 总线两端需要 120Ω 终端电阻
3. **线缆长度**：建议使用双绞线，长度不超过 40m（1Mbps 波特率）

### 串口接线
1. **仅用于调试**：串口仅用于参数配置和固件升级，不用于实时控制
2. **波特率**：921600 bps
3. **连接时机**：可在电机上电前或上电后连接

---

## 多机串联接线示例

电机支持多机串联，方便走线：

```
电源 ──┬─→ 电机1 (接口1) ──→ 电机1 (接口2) ──┬─→ 电机2 (接口1) ──→ ...
       │                                      │
       └─→ CAN_H/CAN_L 总线 ─────────────────┘
```

**优点**：
- 减少接线数量
- 方便布线
- 统一供电

**注意**：
- 确保电源容量足够
- 每个电机设置不同的 CAN ID

---

**返回** [00_目录.md](00_目录.md)  
**上一章** [02_产品规格.md](02_产品规格.md)  
**下一章** [04_工作模式.md](04_工作模式.md)

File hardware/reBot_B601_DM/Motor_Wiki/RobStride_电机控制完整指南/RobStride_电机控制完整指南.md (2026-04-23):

# RobStride 电机控制完整指南

> 发布时间: 2025-11-19T00:00:00.000Z
> 原文链接: https://wiki.seeedstudio.com/cn/robstride_control/

---
On this page

> 高性能 RobStride 电机控制基线，提供 Python、C++、Rust 和 Arduino 实现

License Platform Language

## 📋 目录[](#-目录 "Direct link to 📋 目录")

-   [项目概述](#%E9%A1%B9%E7%9B%AE%E6%A6%82%E8%BF%B0)
-   [支持的电机型号](#%E6%94%AF%E6%8C%81%E7%9A%84%E7%94%B5%E6%9C%BA%E5%9E%8B%E5%8F%B7)
-   [技术架构](#%E6%8A%80%E6%9C%AF%E6%9E%B6%E6%9E%84)
-   [快速开始](#%E5%BF%AB%E9%80%9F%E5%BC%80%E5%A7%8B)
-   [Python 实现](#Python-%E5%AE%9E%E7%8E%B0)
-   [C++ 实现](#C-%E5%AE%9E%E7%8E%B0)
-   [Rust 实现](#Rust-%E5%AE%9E%E7%8E%B0)
-   [Arduino 实现](#Arduino-%E5%AE%9E%E7%8E%B0)
-   [协议详情](#%E5%8D%8F%E8%AE%AE%E8%AF%A6%E6%83%85)
-   [性能优化](#%E6%80%A7%E8%83%BD%E4%BC%98%E5%8C%96)
-   [故障排除](#%E6%95%85%E9%9A%9C%E6%8E%92%E9%99%A4)
-   [开发指南](#%E5%BC%80%E5%8F%91%E6%8C%87%E5%8D%97)

* * *

## 🎯 项目概述[](#-项目概述 "Direct link to 🎯 项目概述")

RobStride 控制库是专为 RobStride 系列电机设计的高性能电机控制库。该项目提供完整的电机控制解决方案，支持多种编程语言和硬件平台，适用于机器人技术、自动化控制、精密定位等各种应用场景。

### 核心特性[](#核心特性 "Direct link to 核心特性")

-   ✅ **多语言支持**：提供 Python、C++、Rust 和 Arduino 实现
-   ✅ **多种控制模式**：MIT 模式、位置模式、速度模式
-   ✅ **实时性能**：50-200Hz 控制频率，低延迟
-   ✅ **工业级稳定性**：支持连续长期运行
-   ✅ **跨平台兼容**：Linux 系统、ESP32 及其他嵌入式平台
-   ✅ **标准化接口**：统一的 API 设计，便于语言切换

### 技术优势[](#技术优势 "Direct link to 技术优势")

-   **高性能**：直接 SocketCAN 通信，无中间件开销
-   **内存安全**：Rust 实现提供内存安全保证
-   **实时控制**：C++ 实现达到 200Hz 控制频率
-   **易于使用**：Python 实现提供友好的交互界面
-   **嵌入式友好**：Arduino 实现适用于资源受限环境

* * *

## 支持的电机型号[](#支持的电机型号 "Direct link to 支持的电机型号")

| 型号 | 最大扭矩 | 最大速度 | KP 范围 | KD 范围 |
|---|---|---|---|---|
| RS-00 | 17 Nm | 50 rad/s | 500.0 | 5.0 |
| RS-01 | 17 Nm | 44 rad/s | 500.0 | 5.0 |
| RS-02 | 17 Nm | 44 rad/s | 500.0 | 5.0 |
| RS-03 | 60 Nm | 50 rad/s | 5000.0 | 100.0 |
| RS-04 | 120 Nm | 15 rad/s | 5000.0 | 100.0 |
| RS-05 | 17 Nm | 33 rad/s | 500.0 | 5.0 |
| RS-06 | 60 Nm | 20 rad/s | 5000.0 | 100.0 |

* * *

## 技术架构[](#技术架构 "Direct link to 技术架构")

### 系统架构图[](#系统架构图 "Direct link to 系统架构图")

```
graph TB
    A[Application Layer] --> B[Control Library]
    B --> C[CAN Protocol Layer]
    C --> D[Hardware Interface Layer]
    D --> E[CAN Hardware]
    B --> F[Python Implementation]
    B --> G[C++ Implementation]
    B --> H[Rust Implementation]
    B --> I[Arduino Implementation]
    C --> J[MIT Mode]
    C --> K[Position Mode]
    C --> L[Speed Mode]
```

### 通信协议[](#通信协议 "Direct link to 通信协议")

-   **物理层**：CAN 2.0B 标准
-   **数据链路层**：扩展帧格式（29 位 ID）
-   **应用层**：自定义 RobStride 协议
-   **传输速率**：1 Mbps

### 控制模式详情[](#控制模式详情 "Direct link to 控制模式详情")

#### 1\. MIT 模式（模式 0）[](#1-mit-模式模式-0 "Direct link to 1. MIT 模式（模式 0）")

-   **特点**：直接扭矩控制，响应速度快
-   **使用场景**：需要快速响应的应用
-   **控制参数**：P、D、T、位置、速度

#### 2\. 位置模式（模式 1）[](#2-位置模式模式-1 "Direct link to 2. 位置模式（模式 1）")

-   **特点**：位置闭环控制，精确定位
-   **使用场景**：精密定位、机器人关节控制
-   **控制参数**：位置、速度、最大扭矩

#### 3\. 速度模式（模式 2）[](#3-速度模式模式-2 "Direct link to 3. 速度模式（模式 2）")

-   **特点**：速度闭环控制，稳定调速
-   **使用场景**：需要恒定速度的应用
-   **控制参数**：速度、最大扭矩

* * *

## 快速开始[](#快速开始 "Direct link to 快速开始")

### 环境设置[](#环境设置 "Direct link to 环境设置")

```bash
sudo apt-get update
sudo apt-get install -y \
    build-essential cmake \
    python3 python3-pip \
    rustc cargo \
    can-utils \
    gcc-avr avr-libc arduino-core
sudo modprobe can
sudo ip link set can0 type can bitrate 1000000
sudo ip link set up can0
```

### 克隆项目[](#克隆项目 "Direct link to 克隆项目")

```bash
git clone https://github.com/Seeed-Projects/RobStride_Control.git
cd RobStride_Control
```

### 选择您的语言实现[](#选择您的语言实现 "Direct link to 选择您的语言实现")

| 语言 | 控制频率 | 内存使用 | 使用场景 |
|---|---|---|---|
| Python | 50-100Hz | ~50MB | 快速原型开发、算法验证 |
| C++ | 200Hz | ~10MB | 高性能应用、实时控制 |
| Rust | 150Hz | ~8MB | 安全关键、内存安全要求 |
| Arduino | 100Hz | ~2KB | 嵌入式、资源受限环境 |

* * *

## Python 实现[](#python-实现 "Direct link to Python 实现")

### 安装依赖[](#安装依赖 "Direct link to 安装依赖")

```bash
cd python
pip install -r requirements.txt
```

### 基本用法[](#基本用法 "Direct link to 基本用法")

```python
from robstride_dynamics import RobstrideBus

bus = RobstrideBus('can0')
motors = bus.scan_channel()
print(f"Found motors: {motors}")

motor_id = 1
target_position = 0.0

while True:
    bus.write_operation_frame(
        motor_id=motor_id,
        p_des=target_position,
        v_des=0.0,
        kp=30.0,
        kd=0.5,
        t_ff=0.0
    )

    response = bus.read_frame(motor_id)
    print(f"Position: {response['position']:.3f} rad")
    time.sleep(0.01)
```

### 交互界面[](#交互界面 "Direct link to 交互界面")

```bash
python3 src/position_control.py 1
python3 src/velocity_control.py 1
```

### 交互命令[](#交互命令 "Direct link to 交互命令")

```
kp 30.0     # 设置 KP 参数
kd 0.5      # 设置 KD 参数
pos 1.0     # 设置目标位置
vel 2.0     # 设置目标速度
tor 5.0     # 设置目标扭矩
quit        # 退出
```

### 高级功能[](#高级功能 "Direct link to 高级功能")

```python
motors = [1, 2, 3, 4]
bus.enable_motors(motors)

for motor_id in motors:
    bus.set_motor_param(motor_id, kp=50.0, kd=1.0)

while True:
    for i, motor_id in enumerate(motors):
        position = math.sin(time.time() + i * math.pi/2)
        bus.write_operation_frame(motor_id, position, 0, 50.0, 1.0, 0)
```

* * *

## C++ 实现[](#c-实现 "Direct link to C++ 实现")

### 构建[](#构建 "Direct link to 构建")

```bash
cd cpp
mkdir build && cd build
cmake ..
make
```

### 基本用法[](#基本用法-1 "Direct link to 基本用法")

```cpp
#include <iostream>
#include <thread>
#include <chrono>
#include <atomic>

class RobStrideMotor {
private:
    int can_socket;
    int motor_id;
    std::atomic<bool> running;

public:
    RobStrideMotor(int id) : motor_id(id), running(false) {
        can_socket = socket(PF_CAN, SOCK_RAW, CAN_RAW);
    }

    void start() {
        running = true;
        std::thread control_thread(&RobStrideMotor::control_loop, this);
        control_thread.detach();
    }

    void set_position(double position, double kp, double kd) {
        uint8_t data[8];

        struct can_frame frame;
        frame.can_id = 0x200 + motor_id;
        frame.can_dlc = 8;
        memcpy(frame.data, data, 8);
        write(can_socket, &frame, sizeof(frame));
    }
};
```
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

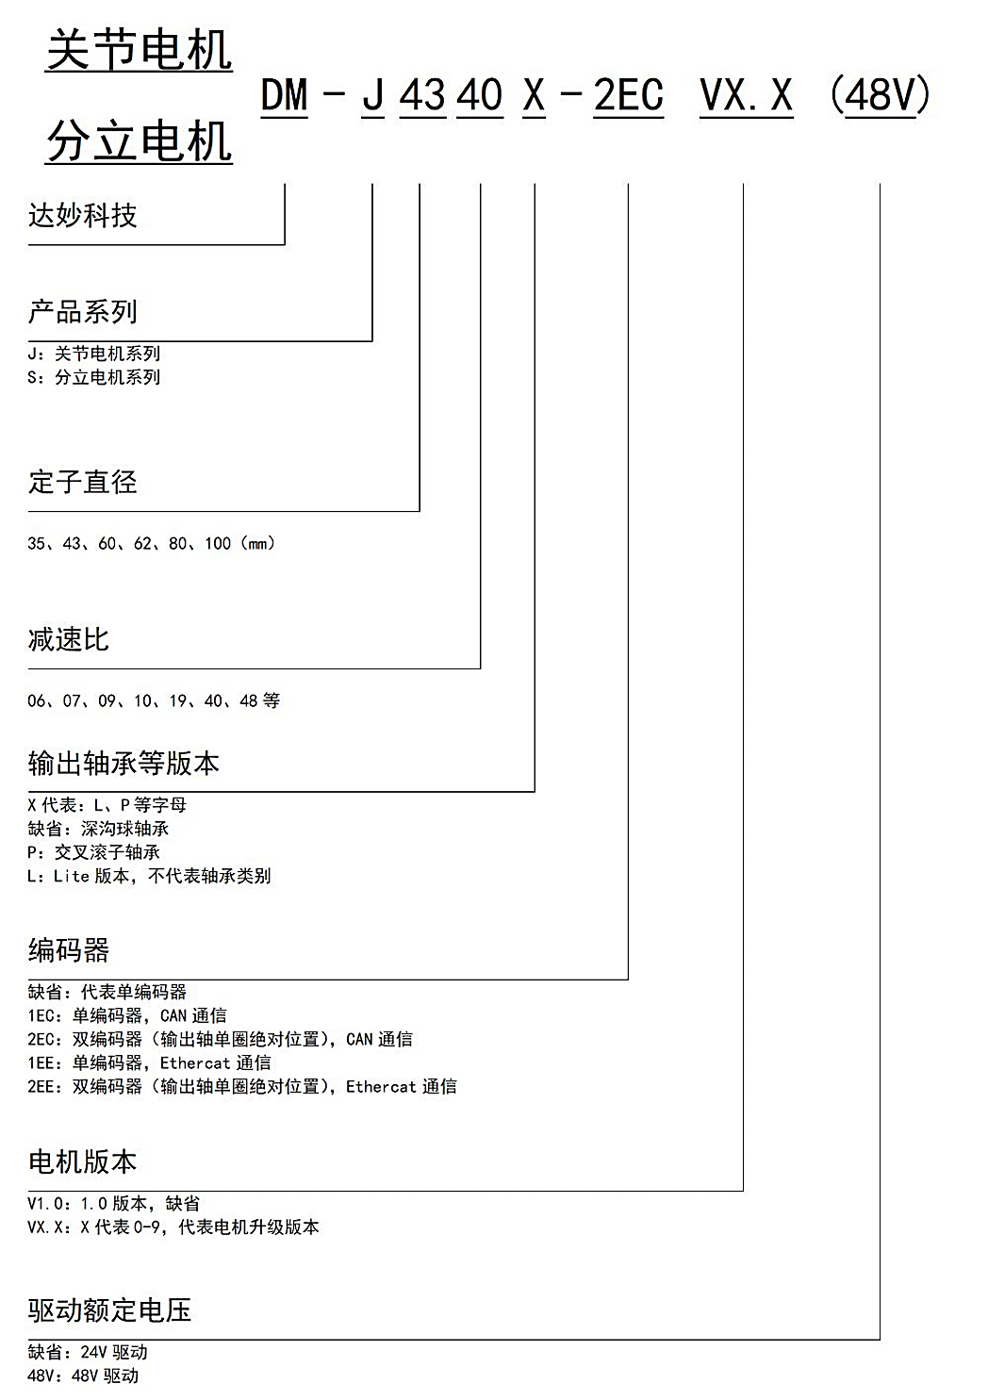
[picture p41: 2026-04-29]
hardware/reBot_B601_DM/Motor_Datasheets/docs_md/images/page_05_img_00.png

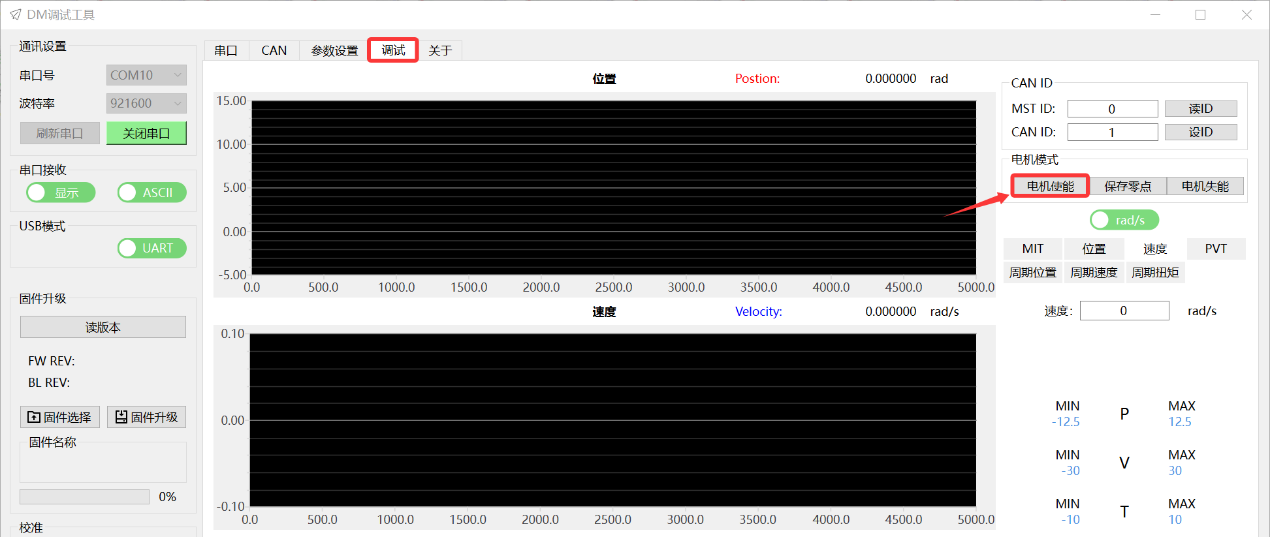
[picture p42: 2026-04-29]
hardware/reBot_B601_DM/Motor_Datasheets/docs_md/images/page_38_img_01.png

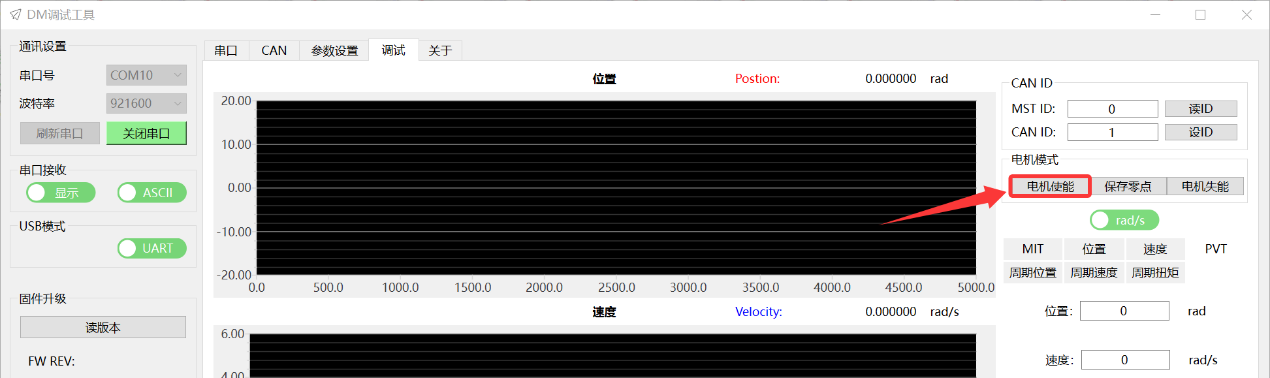
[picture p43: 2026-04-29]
hardware/reBot_B601_DM/Motor_Datasheets/docs_md/images/page_40_img_02.png

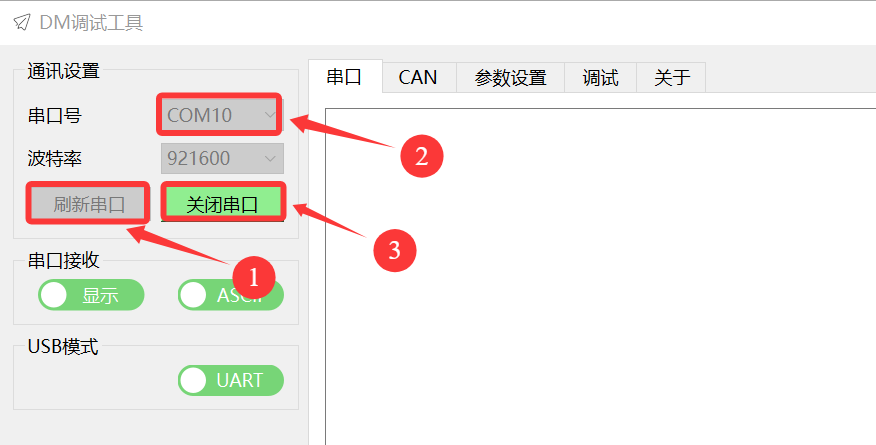
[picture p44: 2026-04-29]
hardware/reBot_B601_DM/Motor_Datasheets/docs_md/images/page_19_img_00.png

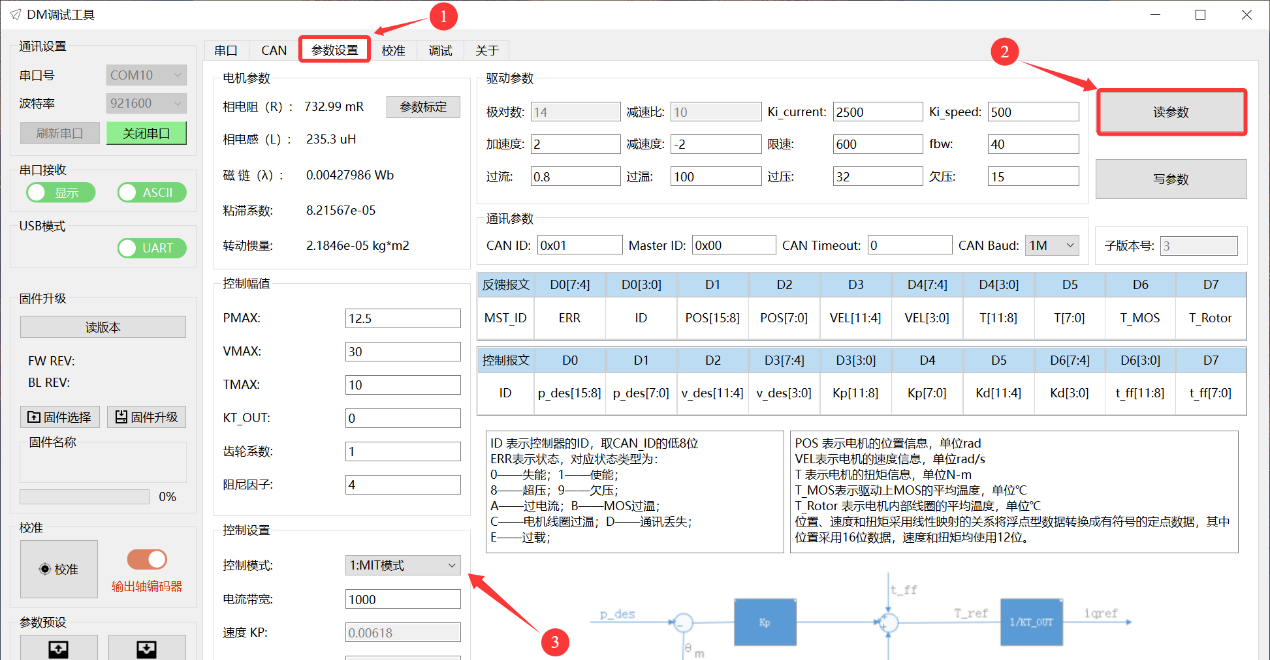
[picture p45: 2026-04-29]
hardware/reBot_B601_DM/Motor_Datasheets/docs_md/images/page_27_img_02.png

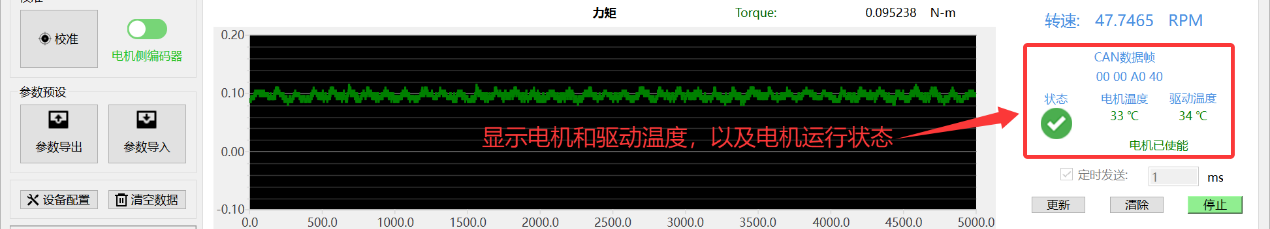
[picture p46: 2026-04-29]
hardware/reBot_B601_DM/Motor_Datasheets/docs_md/images/page_39_img_01.png

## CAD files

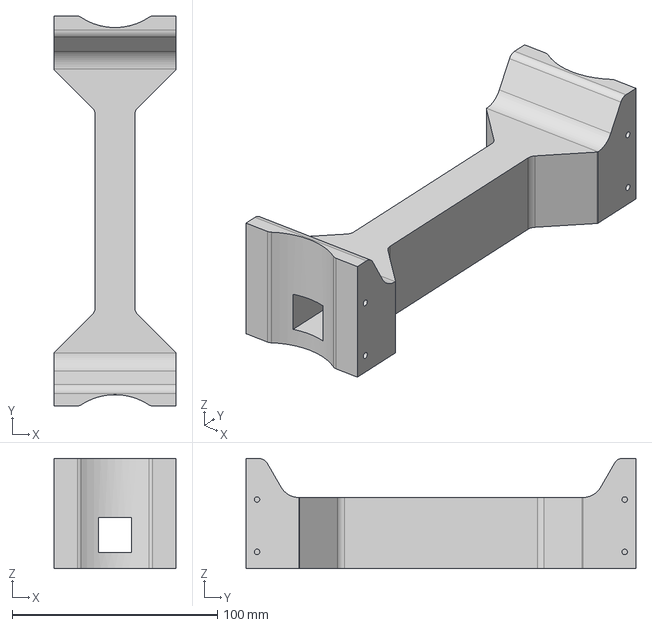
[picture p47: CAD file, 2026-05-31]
hardware/reBot_B601_DM/3D_Printed_Parts/01_Upper_Arm_Fuller_M.step
59.4 x 189.9 x 53.6 mm

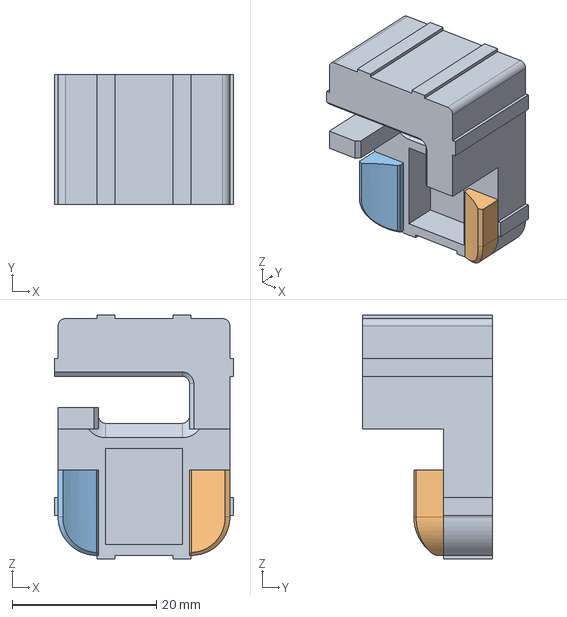
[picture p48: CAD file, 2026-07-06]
hardware/reBot_B601_DM/3D_Printed_Parts/DM_Motor1_wiring_harness_clip.stp
24.8 x 18.0 x 33.8 mm

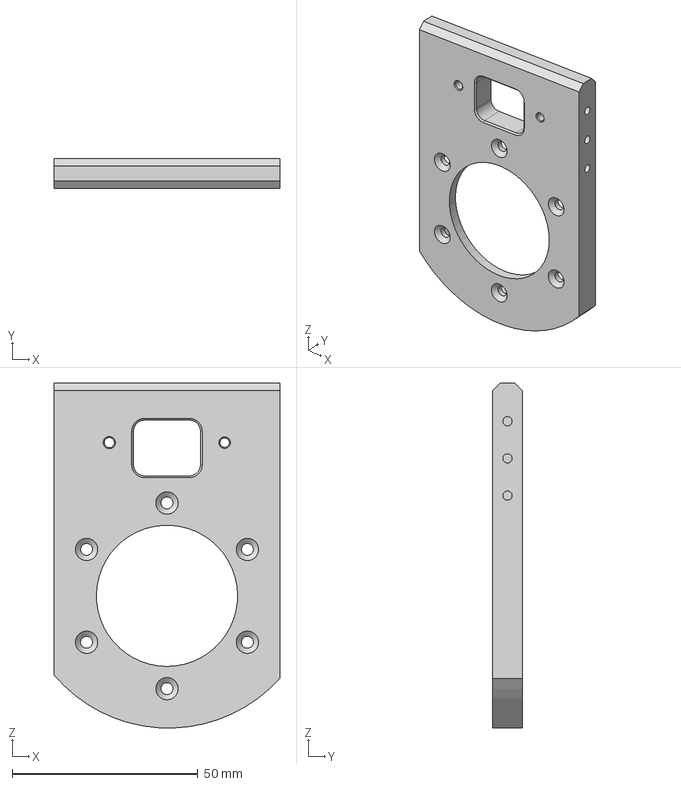
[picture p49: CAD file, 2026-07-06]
hardware/reBot_B601_DM/Metal_Parts/02_Wrist_Bracket.step
60.8 x 8.00 x 92.9 mm

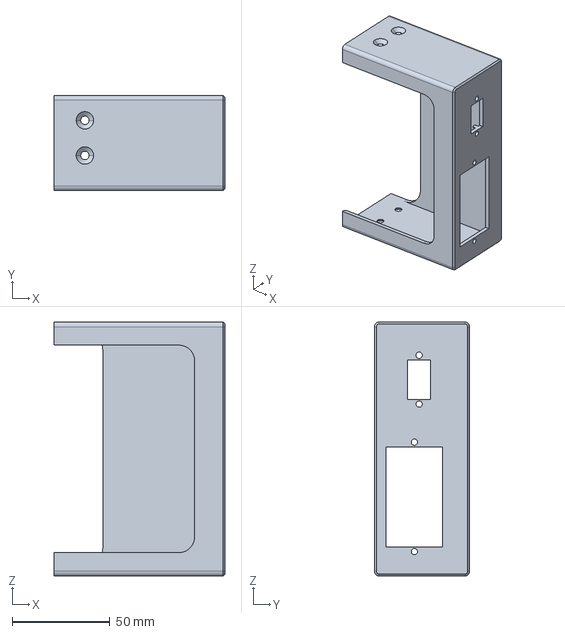
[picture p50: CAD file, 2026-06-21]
hardware/reBot_B601_RS/3D_Printed_Parts/RS-power-Top Cover.stp
87.5 x 48.8 x 130.0 mm

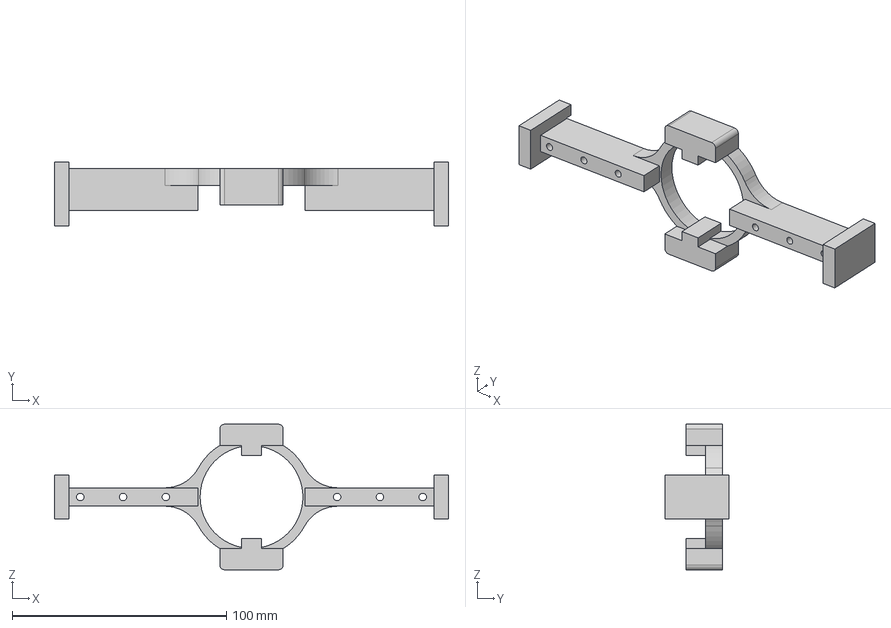
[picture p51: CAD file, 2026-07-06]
hardware/reBot_B601_DM/3D_Printed_Parts/01_Rail_Bracket.step
184.1 x 30.0 x 68.1 mm

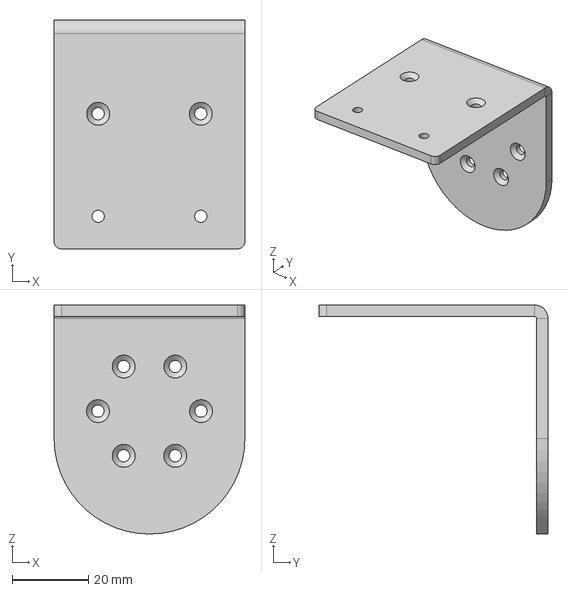
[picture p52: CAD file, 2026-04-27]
hardware/reBot_B601_DM/Metal_Parts/03_Link5.step
50.0 x 60.0 x 60.0 mm

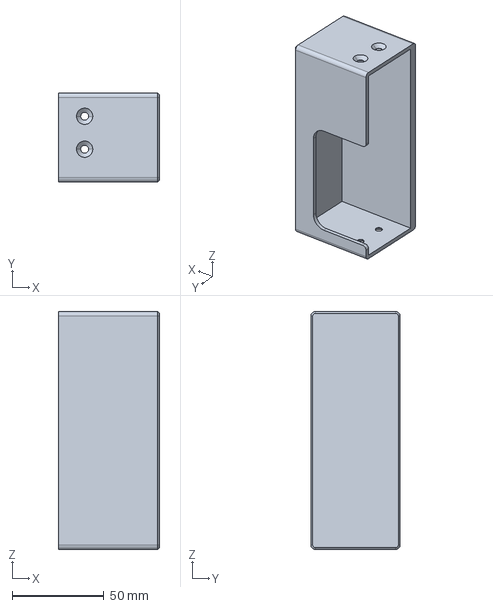
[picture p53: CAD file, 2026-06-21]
hardware/reBot_B601_RS/3D_Printed_Parts/RS-power-Bottom Cover.stp
55.0 x 48.8 x 130.0 mm

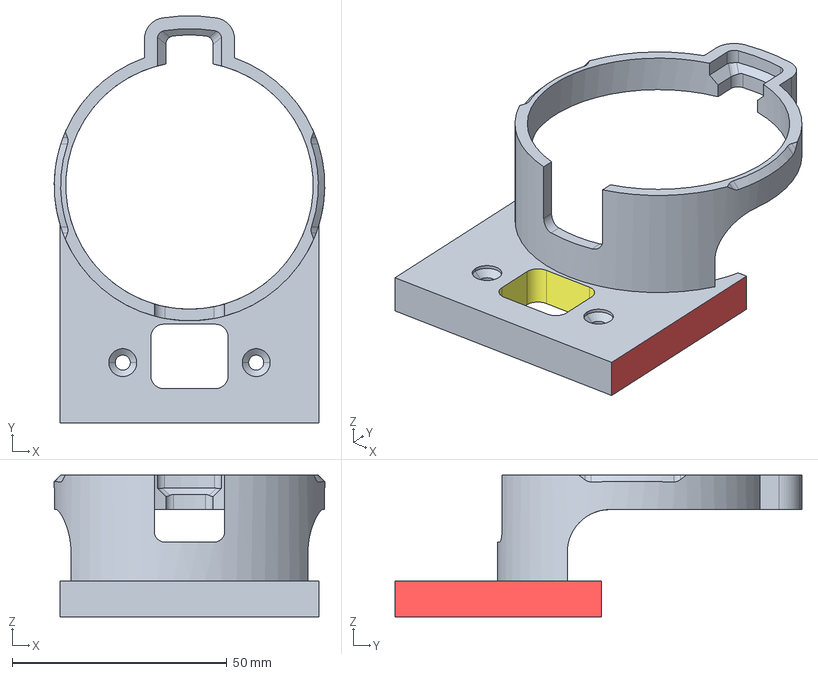
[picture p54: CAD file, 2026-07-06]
hardware/reBot_B601_DM/3D_Printed_Parts/01_Motor_Cover.step
63.0 x 94.8 x 33.0 mm

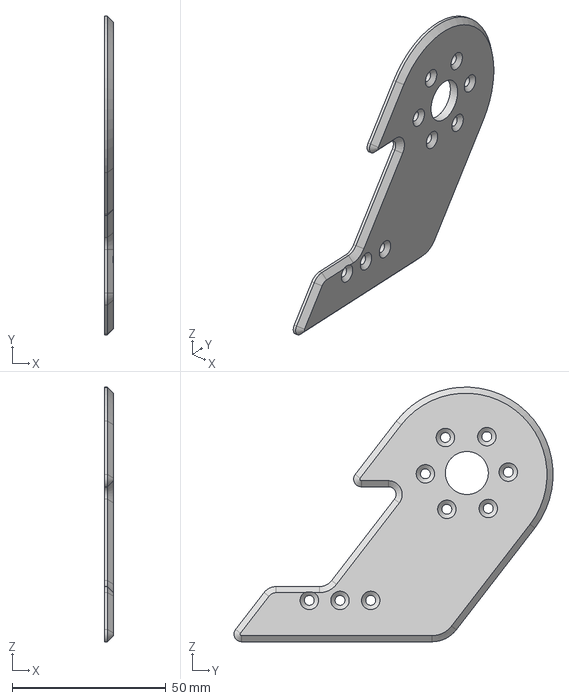
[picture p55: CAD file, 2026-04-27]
hardware/reBot_B601_DM/Metal_Parts/02_Lower_Wrist_Link_R.step
3.00 x 103.9 x 82.9 mm

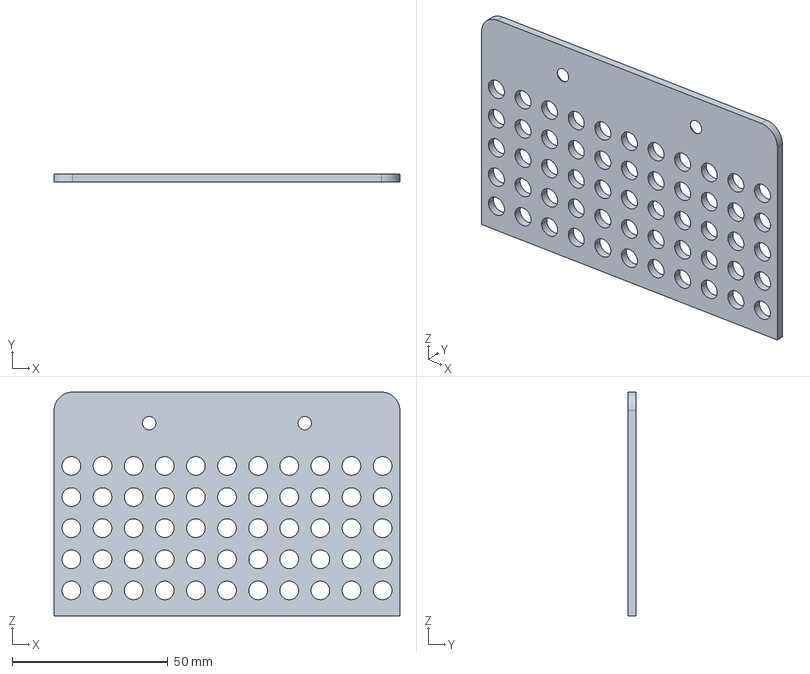
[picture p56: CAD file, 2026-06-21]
hardware/reBot_B601_RS/3D_Printed_Parts/RS-power-Top Cover-Sliding Cover.stp
111.2 x 2.45 x 71.9 mm

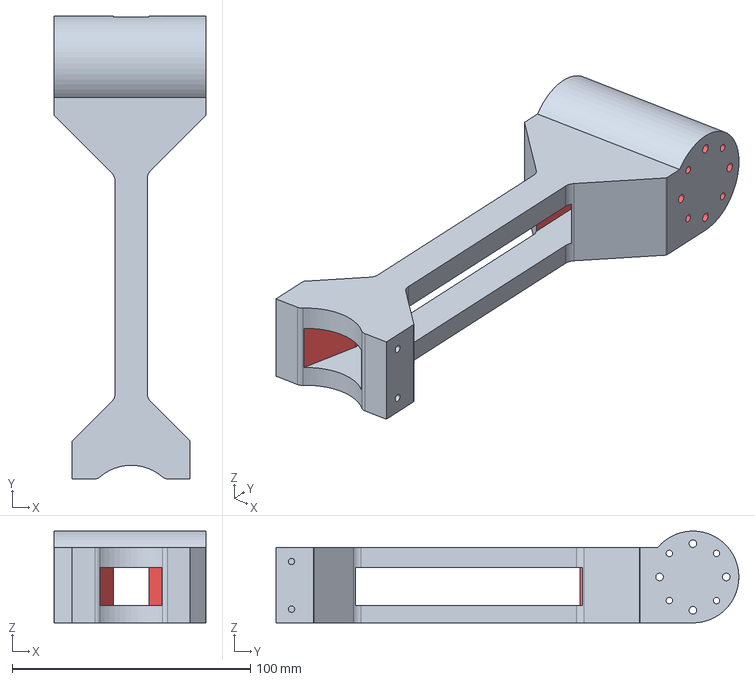
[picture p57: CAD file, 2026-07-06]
hardware/reBot_B601_DM/3D_Printed_Parts/01_Lower_Arm_Filler_M.step
63.8 x 194.4 x 38.6 mm

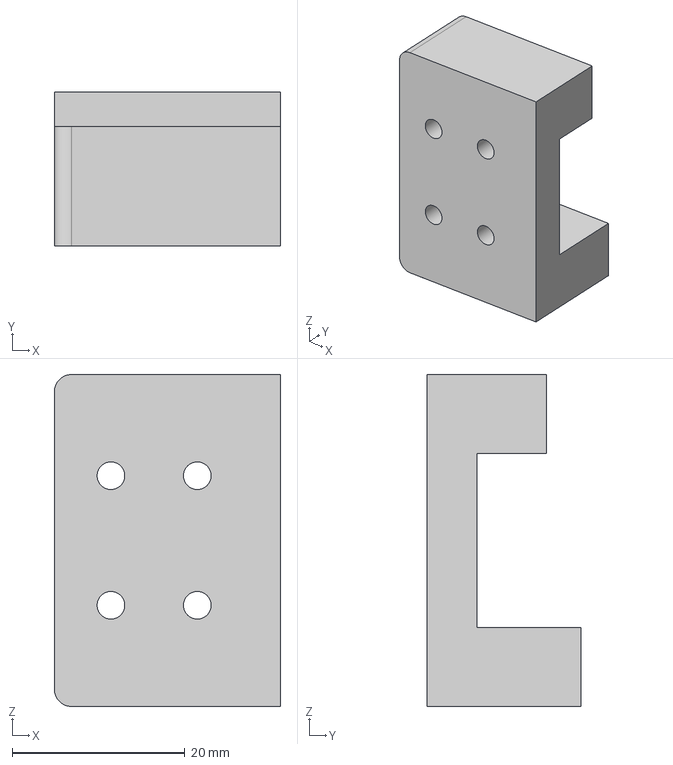
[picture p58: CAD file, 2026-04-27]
hardware/reBot_B601_DM/Metal_Parts/02_Slider_Extension.step
26.2 x 17.8 x 38.4 mm

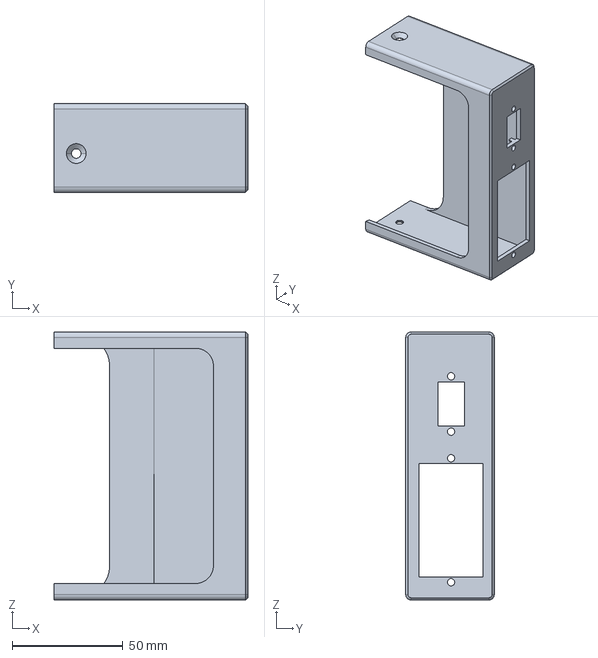
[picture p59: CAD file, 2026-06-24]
hardware/reBot_B601_DM/3D_Printed_Parts/DM-power-Top Cover.stp
87.5 x 40.0 x 121.0 mm

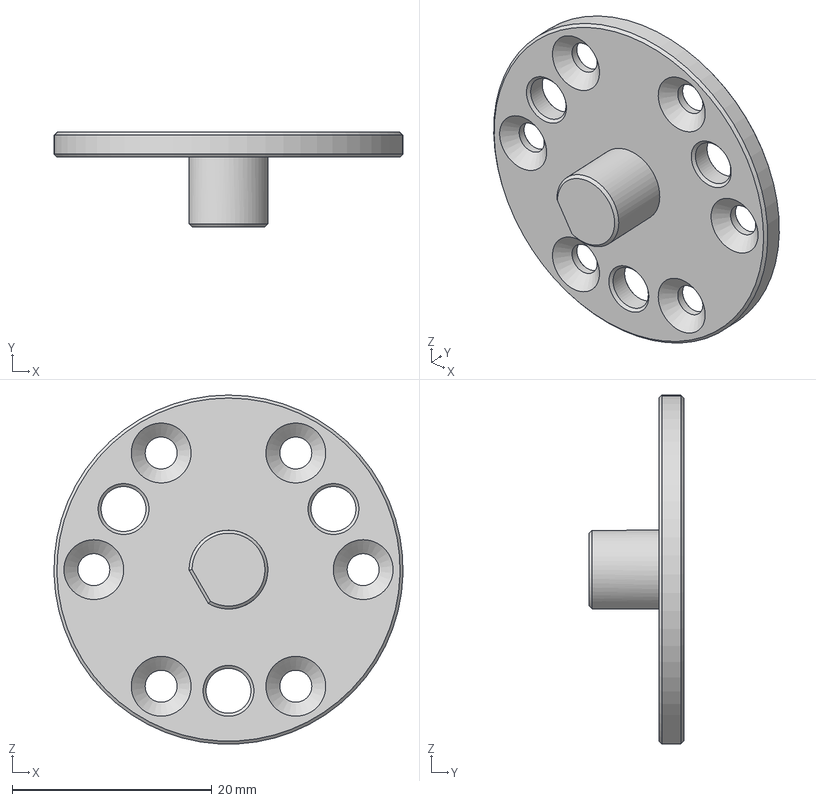
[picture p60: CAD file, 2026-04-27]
hardware/reBot_B601_DM/Metal_Parts/02_Gear_Connector.step
35.0 x 9.50 x 35.0 mm

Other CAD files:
hardware/reBot_B601_DM/3D_Printed_Parts/DM-power-Top Cover-Sliding Cover.stp
hardware/reBot_B601_DM/Metal_Parts/02_Motor_Front_Spacer.step
hardware/reBot_B601_DM/3D_Printed_Parts/DM-power-Bottom Cover.stp
hardware/reBot_B601_DM/Metal_Parts/02_Motor_Back_Spacer.step
hardware/reBot_B601_DM/3D_Printed_Parts/01_BASE_Link.step
hardware/reBot_B601_DM/3D_Printed_Parts/01_Joint5_Cable Restraint_A.step
hardware/reBot_B601_DM/3D_Printed_Parts/01_Joint6_7_Cable Restraint_A.step
hardware/reBot_B601_DM/3D_Printed_Parts/01_Joint6_7_Cable Restraint_B.step
hardware/reBot_B601_DM/3D_Printed_Parts/D405_305_Mount.step
hardware/reBot_B601_DM/3D_Printed_Parts/D435_Gemini2_Mount.step
hardware/reBot_B601_DM/3D_Printed_Parts/Soft_Gripper_Finger.step
hardware/reBot_B601_DM/3D_Printed_Parts/Soft_Gripper_Mount.step
hardware/reBot_B601_DM/3D_Printed_Parts/UVC32_mount.step
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

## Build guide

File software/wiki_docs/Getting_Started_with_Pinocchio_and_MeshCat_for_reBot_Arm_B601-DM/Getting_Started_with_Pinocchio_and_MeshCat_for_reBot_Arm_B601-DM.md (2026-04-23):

# Getting Started with Pinocchio and MeshCat for reBot Arm B601-DM

> 发布时间: 2026-03-24T00:00:00.000Z
> 原文链接: https://wiki.seeedstudio.com/rebot_arm_b601_dm_pinocchio_meshcat/

---
On this page

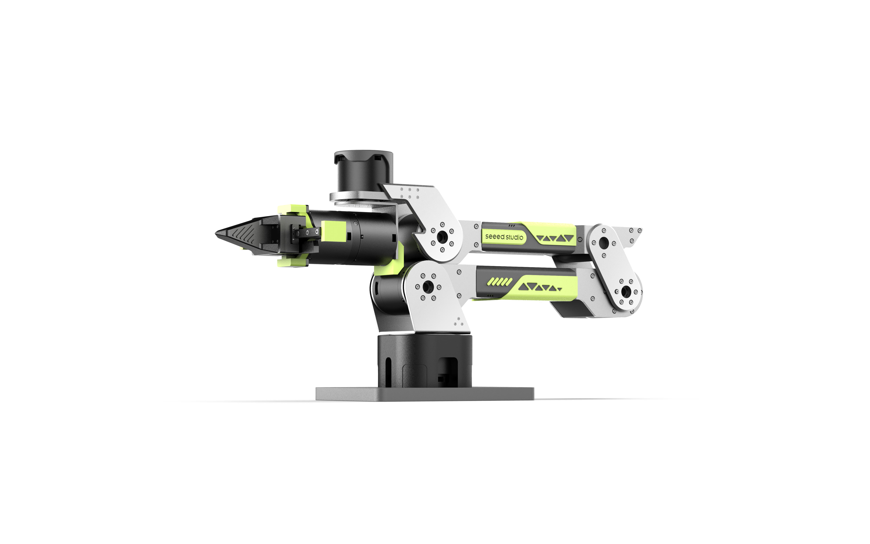
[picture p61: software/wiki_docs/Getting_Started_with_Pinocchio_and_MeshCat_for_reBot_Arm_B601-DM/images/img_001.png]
traj\_sim\_geodesic


License: MITPython VersionPlatformPinocchio

**6-DOF Robotic Arm · Multi-Motor Support · Kinematics Solver · Trajectory Planning · Fully Open Source**

* * *

## 📖 Introduction[](#-introduction "Direct link to 📖 Introduction")

**reBotArm Control** is a Python control library for the reBot Arm B601 robotic arm, providing a complete solution from low-level motor control to high-level kinematics computation.

### ✨ Core Features[](#-core-features "Direct link to ✨ Core Features")

-   🦾 **Dual Model Support** — B601-DM (Damiao motors) and B601-RS (RobStride motors)
-   🧮 **Kinematics Solver** — Forward/Inverse kinematics based on Pinocchio
-   🛤️ **Trajectory Planning** — SE(3) geodesic trajectory + CLIK tracking
-   🔧 **Flexible Configuration** — YAML configuration file for quick hardware adaptation

* * *

## ⚙️ Quick Start[](#️-quick-start "Direct link to ⚙️ Quick Start")

### Requirements[](#requirements "Direct link to Requirements")

Item

Requirement

**Python**

3.10+

**Operating System**

Ubuntu 22.04+

**Communication Interface**

USB2CAN Serial Bridge or CAN Interface

### Installation Steps[](#installation-steps "Direct link to Installation Steps")

#### Step 1. Install uv (if not installed)[](#step-1-install-uv-if-not-installed "Direct link to Step 1. Install uv (if not installed)")

```
curl -LsSf https://astral.sh/uv/install.sh | sh
```

#### Step 2. Sync Environment (Install All Dependencies)[](#step-2-sync-environment-install-all-dependencies "Direct link to Step 2. Sync Environment (Install All Dependencies)")

```
git clone https://github.com/vectorBH6/reBotArm_control_py.gitcd reBotArm_control_pyuv sync
```

tip

`uv sync` will automatically create a virtual environment (if it doesn't exist) and install all dependencies according to `pyproject.toml` and `uv.lock`.

* * *

## 🔌 Hardware Configuration[](#-hardware-configuration "Direct link to 🔌 Hardware Configuration")

### Default: Damiao USB2CAN Serial Bridge[](#default-damiao-usb2can-serial-bridge "Direct link to Default: Damiao USB2CAN Serial Bridge")

reBot Arm B601-DM uses the Damiao USB2CAN serial bridge module by default.

**Hardware Connection**:

1.  Connect the USB2CAN module to your computer via USB cable
2.  The system will automatically recognize it as `/dev/ttyACM0` device

**Configuration Verification**:

```
ls /dev/ttyACM0motorbridge-cli scan --vendor damiao --transport dm-serial \    --serial-port /dev/ttyACM0 --serial-baud 921600
```

### Optional: Standard CAN Interface[](#optional-standard-can-interface "Direct link to Optional: Standard CAN Interface")

Using other USB-CAN adapters (CANable, PCAN, etc.):

```
sudo ip link set can0 up type can bitrate 500000ip -details link show can0
```

### Motor Brand Configuration[](#motor-brand-configuration "Direct link to Motor Brand Configuration")

Motor Brand

Transmission

Configuration

Baud Rate

**Damiao**

Serial Bridge

`dm-serial`

921600

**Damiao**

CAN Interface

`socketcan`

500000

**RobStride**

CAN Interface

`socketcan`

500000

tip

-   For Damiao motors using serial bridge, must set `--transport dm-serial`
-   Feedback ID rule: `feedback_id = motor_id + 0x10`

* * *

## 📁 Project Structure[](#-project-structure "Direct link to 📁 Project Structure")

```
reBotArm_control_py/├── config/                     # Configuration files│   └── robot.yaml              # Joint parameter configuration├── example/                    # Example programs│   ├── Debug Tools/│   │   ├── 1_damiao_text.py        # Single motor console│   │   └── 2_zero_and_read.py      # Zero calibration│   ├── Kinematics Tests/│   │   ├── 5_fk_test.py            # Forward kinematics│   │   └── 6_ik_test.py            # Inverse kinematics│   ├── Real Machine Control/│   │   ├── 7_arm_ik_control.py     # IK real-time control│   │   ├── 8_arm_traj_control.py   # Trajectory planning│   │   └── 9_gravity_compensation.py  # Gravity compensation│   └── sim/                    # Simulation tools├── reBotArm_control_py/        # Core library│   ├── actuator/               # Actuator module│   ├── kinematics/             # Kinematics module│   ├── controllers/            # Controller module│   └── trajectory/             # Trajectory planning module├── urdf/                       # URDF model└── README.md
```

* * *

## 🎮 Example Programs[](#-example-programs "Direct link to 🎮 Example Programs")

### Debug Tools[](#debug-tools "Direct link to Debug Tools")

#### 1️⃣ Single Motor Console (`1_damiao_text.py`)[](#1️⃣-single-motor-console-1_damiao_textpy "Direct link to 1️⃣-single-motor-console-1_damiao_textpy")

Direct motorbridge SDK single motor testing with three control modes.

**Usage**:

```
uv run python example/1_damiao_text.py
```

**Interactive Commands**:

Command

Description

`mit <pos_deg> [vel kp kd tau]`

MIT mode

`posvel <pos_deg> [vlim]`

POS\_VEL mode

`vel <vel_rad_s>`

Velocity mode

`enable` / `disable`

Enable/Disable

`set_zero`

Set zero position

`state`

View state

* * *

#### 2️⃣ Zero Calibration & Angle Monitor (`2_zero_and_read.py`)[](#2️⃣-zero-calibration--angle-monitor-2_zero_and_readpy "Direct link to 2️⃣-zero-calibration--angle-monitor-2_zero_and_readpy")

Automatically set all joint zeros and display joint angles in real-time.

**Usage**:

```
uv run python example/2_zero_and_read.py
```

* * *

### Kinematics Tests[](#kinematics-tests "Direct link to Kinematics Tests")

#### 5️⃣ Forward Kinematics Test (`5_fk_test.py`)[](#5️⃣-forward-kinematics-test-5_fk_testpy "Direct link to 5️⃣-forward-kinematics-test-5_fk_testpy")

Calculate end-effector pose from joint angles.

**Input**: 6 joint angles (degrees)

**Output**:

-   End-effector position (X, Y, Z) — Unit: meters
-   Rotation matrix (3×3)
-   Euler angles (Roll/Pitch/Yaw) — Unit: degrees

**Example**:

```
uv run python example/5_fk_test.py> 0 0 0 0 0 0> 45 -30 15 -60 90 180
```

* * *

#### 6️⃣ Inverse Kinematics Test (`6_ik_test.py`)[](#6️⃣-inverse-kinematics-test-6_ik_testpy "Direct link to 6️⃣-inverse-kinematics-test-6_ik_testpy")

Solve joint angles from desired end-effector pose.

**Input Format**:

-   Position only: `<x> <y> <z>` (meters)
-   Position + Orientation: `<x> <y> <z> <roll> <pitch> <yaw>` (degrees)

**Example**:

```
uv run python example/6_ik_test.py> 0.25 0.0 0.15              > 0.25 0.0 0.15 0 0 0
```

* * *

### Real Machine Control[](#real-machine-control "Direct link to Real Machine Control")

Permission Setup

Before running real machine control examples, you need to set device permissions:

```
sudo chmod 666 /dev/ttyACM0sudo chmod 666 /dev/can0
```

#### 7️⃣ IK Real-time Control (`7_arm_ik_control.py`)[](#7️⃣-ik-real-time-control-7_arm_ik_controlpy "Direct link to 7️⃣-ik-real-time-control-7_arm_ik_controlpy")

Real-time end-effector control based on IK solver.

**Interactive Commands**:

Command

Description

`x y z [roll pitch yaw]`

Target end-effector pose

`state`

View current/target state

`pos`

Current end-effector position

`q/quit/exit`

Quit

**Usage**:

```
uv run python example/7_arm_ik_control.py> 0.3 0.0 0.2> 0.3 0.1 0.25 0 0.5 0
```

* * *

#### 8️⃣ Trajectory Planning Control (`8_arm_traj_control.py`)[](#8️⃣-trajectory-planning-control-8_arm_traj_controlpy "Direct link to 8️⃣-trajectory-planning-control-8_arm_traj_controlpy")

SE(3) geodesic trajectory planning + CLIK tracking.

**Input Format**:

```
x y z [roll pitch yaw] [duration]
```

**Parameters**:

-   `x, y, z`: Target position (meters)
-   `roll, pitch, yaw`: Target orientation (radians)
-   `duration`: Movement duration (seconds), default 2.0s

**Usage**:

```
uv run python example/8_arm_traj_control.py> 0.3 0.0 0.3 0 0.4 0 2.0
```

* * *

#### 9️⃣ Gravity Compensation Control (`9_gravity_compensation.py`)[](#9️⃣-gravity-compensation-control-9_gravity_compensationpy "Direct link to 9️⃣-gravity-compensation-control-9_gravity_compensationpy")

Compensates for joint gravity using Pinocchio dynamics model.

**Control Law**:

```
tau = g(q)          — Gravity feedforwardpos = current motor position  — Joint position follows current positionkp = 2,  kd = 1     — Unified stiffness/damping for all motors
```

**Expected Behavior**:

-   The robotic arm can "float" in any posture
-   Won't fall due to its own weight when released
-   Can be manually moved to any position

**Usage**:

```
uv run python example/9_gravity_compensation.py
```

**Output**:

-   Real-time display of expected torque for each joint (N·m)
-   Press `Ctrl+C` to stop and disconnect

* * *

## 📄 License[](#-license "Direct link to 📄 License")

This project is open source under the **MIT License**.

* * *

## ☎ Contact Us[](#-contact-us "Direct link to ☎ Contact Us")

-   **Technical Support**: [Submit Issue](https://github.com/vectorBH6/reBotArm_control_py/issues)
-   **Repository**: [GitHub](https://github.com/vectorBH6/reBotArm_control_py)

* * *

**🌟 If this project helps you, please give us a Star!**

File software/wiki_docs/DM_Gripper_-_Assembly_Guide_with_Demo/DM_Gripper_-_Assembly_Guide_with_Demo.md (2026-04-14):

# DM_Gripper - Assembly Guide with Demo

> 发布时间: 2025-09-17T00:00:00.000Z
> 原文链接: https://wiki.seeedstudio.com/dm_gripper/

---
On this page

The **DM\_Gripper** is an open-source, **3D-printed robotic gripper** designed around the **DM-4310-2EC motor**. Its modular design emphasizes ease of assembly and disassembly, enabling both hobbyists and robotics developers to **rapidly prototype, customize, and scale** their projects.

Fully compatible with **DAMIAO actuators**, the DM\_Gripper also provides flexibility for integration with other actuator brands. Its unique **swappable claw system** allows users to quickly exchange claws of different shapes, supporting diverse robotic tasks and use cases.

All gripper parts are **fully 3D-printable** with minimal support requirements, making it accessible for makers, researchers, and engineers alike.

This wiki includes:

-   Mechanism design overview
-   Full bill of materials (BOM)
-   3D printing guide and setup
-   Step-by-step assembly instructions
-   Demo and practical use cases

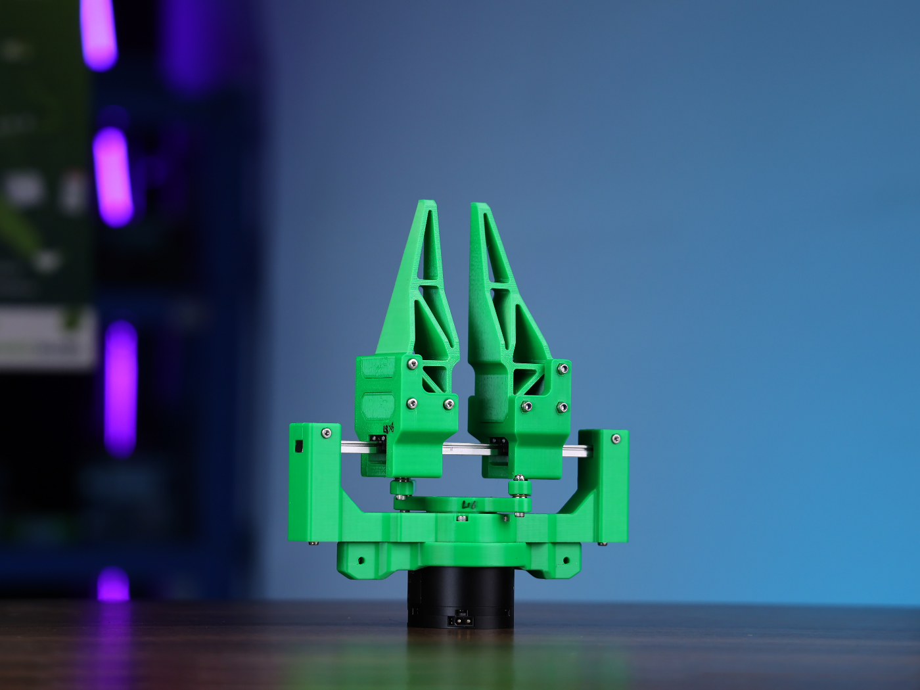
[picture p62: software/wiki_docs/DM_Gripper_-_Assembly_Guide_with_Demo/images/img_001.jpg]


[**Get One Now 🖱️**](https://www.seeedstudio.com/Seeed-Gripper-01-p-6561.html)

## Dimensions/Operating Range[](#dimensionsoperating-range "Direct link to Dimensions/Operating Range")

The dimensions and operating range are shown below in millimeters, with variable height depending on the claws used.

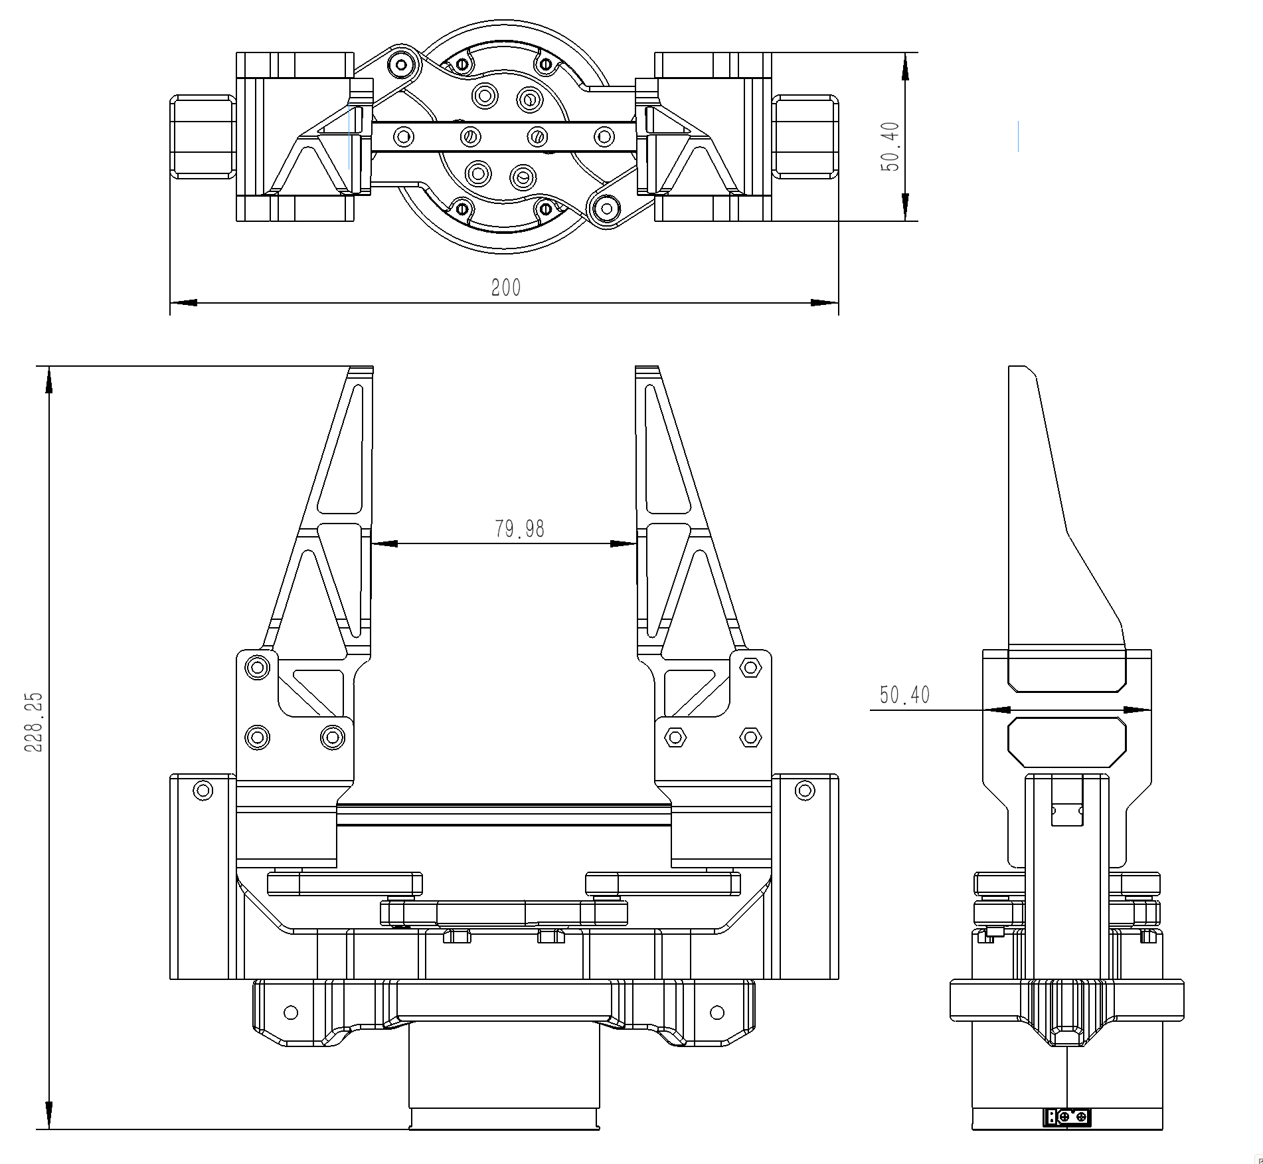
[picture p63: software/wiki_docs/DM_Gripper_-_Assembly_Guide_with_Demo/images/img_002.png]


## Drive Mechanisms[](#drive-mechanisms "Direct link to Drive Mechanisms")

This gripper features a classical Dual Crank & Slider mechanism, translating rotational to axial motion.

-   **Crank & Slider Showcase:**

Crank slider mechanism

-   **Motion Simulation Showcase**

## BOM[](#bom "Direct link to BOM")

#### 🔩 Fasteners[](#-fasteners "Direct link to 🔩 Fasteners")

| Name | Quantity |
|---|---|
| Phillips Pan Head Screw PM3×8 | 8 |
| Hex Socket Cap Screw M3×20 | 4 |
| Hex Socket Cap Screw M3×25 | 6 |
| Hex Socket Cap Screw M3×50 | 8 |
| Hex Socket Cap Screw M3×16 | 12 |
| 304 Nylon Locking Hex Self-Locking Nut M3 (Thickness-3.9mm × Width-5.5mm) | 18 |
| Spring Washer – M3 | 4 |
| Flat Washer – M3×7mm (OD) × 0.5mm (Thickness) | 8 |

#### ⚙️ Bearing[](#️-bearing "Direct link to ⚙️ Bearing")

| Name | Quantity |
|---|---|
| F3-8M Miniature Thrust Bearing (ID-3mm × OD-8mm × Thickness-3.5mm) | 4 |

#### 🛠️ Linear Motion[](#️-linear-motion "Direct link to 🛠️ Linear Motion")

| Name | Quantity |
|---|---|
| Stainless Steel Linear Rail MGN9, 200 mm | 1 |
| Linear Rail Carriage MGN9C (Standard) | 2 |

#### 🔌 Actuator[](#-actuator "Direct link to 🔌 Actuator")

| Name | Quantity |
|---|---|
| DM4310-2EC Motor | 1 |

#### 🧩 Custom Printables[](#-custom-printables "Direct link to 🧩 Custom Printables")

| Name | Quantity |
|---|---|
| **3D Printed Parts** | 1 set |

## Assembly Guide[](#assembly-guide "Direct link to Assembly Guide")

### 3D-Printing Guide[](#3d-printing-guide "Direct link to 3D-Printing Guide")

-   If you have dedicated support material or PETG+PLA in your [**AMS**](https://wiki.bambulab.com/en/ams/manual/ams-function-introduction) and want the best surface finish on supported faces, please refer to [**This Wiki**](https://wiki.bambulab.com/en/filament-acc/filament/h2d-pla-and-petg-mutual-support).
    _Note: your print job may take longer._

-   If you only have one filament to print, make sure you print with the correct orientations and decide whether you need the following steps (Turn On **ADVANCED** in Bambu Studio).

    > **Warning**
    >
    > Do not change the Top Z distance if you are using PETG or ABS. Keep them as default. Only change this if you use PLA.

    -   Step 1: Print layout with minimal supports required

        Crank slider mechanism

    -   Step 2: Scarf Settings provide a better surface finish as marked in Green Rectangles.

        Crank slider mechanism

    -   Step 3: My Print Settings: 0.2mm layer height, 25% infill density, Style – 3D Honeycomb.

        ps1
        ps2
        ps3
        ps4

### Step By Step Assembly Walkthrough[](#step-by-step-assembly-walkthrough "Direct link to Step By Step Assembly Walkthrough")

-   Step 1: Fix the Claw Holders to the MGN9C sliders with eight M3×8 mushroom-headed screws

-   Step 2: Stack the bearings, rotors, and linkages ("hamburger" style)

-   Step 3: Place eight M7 washers above and below the slots

-   Step 4: Place four nuts above and below the washers

-   Step 5: Screw four pairs of M3×20 screws and spring washers to the nuts (use pliers if necessary)

-   Step 6: Place the Base and Actuator in position; the patterns on the rotor plate and actuator should align

-   Step 7: Screw six M3×16 screws to secure the rotor plate to the actuator

-   Step 8: Push the claw base to the maximum range for the next steps

-   Step 9: Attach the cam holder to the bottom

-   Step 10: Fix the cam holder with four pairs of M3×25 screws and nuts

-   Step 11: Fix the base with six M3×16 screws (Pull out the rail for this stage and slide it back in afterwards)

-   Step 12: Use two pairs of M3×50 screws and nuts to lock the rail on the base

-   Step 13: Slide the rail presser in and secure with two pairs of M3×25 screws and nuts

-   Step 14: Place the claws on the claw holders, and secure them with six pairs of M3×50 screws and nuts

## Demos and CAD Files[](#demos-and-cad-files "Direct link to Demos and CAD Files")

-   Follow the [**Damiao Actuators Wiki**](https://wiki.seeedstudio.com/damiao_series/) to get everything set up if you haven't done so.
-   Follow the [**Torque Controller Demo**](https://github.com/tianrking/DM_Gripper/tree/main) (**many thanks to tianrking**) to get the gripper moving with a cool GUI.

Gripper Controller Demo

-   The CAD resources: editable STEP files and STLs are available [**here**](https://github.com/YlsonDdb/DM_Gripper).

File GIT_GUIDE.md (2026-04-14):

# Git 操作指南 — 零基础 Fork 开源项目

> 本文档记录如何 Fork 一个开源项目、添加自己的内容、并保持与官方同步。
> 以本仓库（reBot-DevArm）为实际案例，适合完全不懂 Git 的新手。

---

## 为什么要 Fork？

当你想学习一个开源项目，并在上面添加自己的笔记、文档、改进时，有三种做法：

| 做法 | 优点 | 缺点 |
|---|---|---|
| **直接下载 ZIP** | 简单 | 无法同步官方更新，无法分享给别人 |
| **直接 Clone 官方仓库** | 能拉取更新 | 无法推送自己的修改（没有权限） |
| **Fork 到自己账号** ✅ | 能改、能推送、能同步、能分享 | 需要学一点 Git |

**Fork = 在 GitHub 上复制一份到你的账号，你拥有完全控制权。**

---

## 第一步：在 GitHub 上 Fork 仓库

### 1.1 打开官方仓库

访问你想 Fork 的项目，例如：
```
https://github.com/Seeed-Projects/reBot-DevArm
```

### 1.2 点击右上角的 "Fork" 按钮

Fork 按钮位置

### 1.3 填写 Fork 信息

- **Owner**：你的 GitHub 用户名（自动选中）
- **Repository name**：保持和官方一样就行（例如 `reBot-DevArm`）
- **Description**：官方的描述会自动复制过来
- **Copy the main branch only**：✅ 勾选（只复制主分支，够用了）

Fork 创建页面示例

### 1.4 点击 "Create fork"

等待几秒，GitHub 会自动复制整个仓库到你的账号下。

完成后，你会看到：
- URL 变成了 `https://github.com/你的用户名/reBot-DevArm`
- 顶部显示 "forked from Seeed-Projects/reBot-DevArm"

---

## 第二步：把本地仓库关联到你的 Fork

### 2.1 如果你还没有本地仓库

直接 Clone 你的 Fork：
```bash
git clone https://github.com/你的用户名/reBot-DevArm.git
cd reBot-DevArm
```

然后添加官方仓库作为 upstream（方便以后同步）：
```bash
git remote add upstream https://github.com/Seeed-Projects/reBot-DevArm.git
```

### 2.2 如果你已经有本地仓库（本文档的情况）

查看当前 remote 配置：
```bash
git remote -v
```

如果显示的是官方仓库，需要改成你的 Fork：
```bash
# 将 origin 改为你的 Fork
git remote set-url origin https://github.com/你的用户名/reBot-DevArm.git

# 添加官方仓库为 upstream
git remote add upstream https://github.com/Seeed-Projects/reBot-DevArm.git
```

再次检查：
```bash
git remote -v
```

应该显示：
```
origin    https://github.com/你的用户名/reBot-DevArm.git (fetch)
origin    https://github.com/你的用户名/reBot-DevArm.git (push)
upstream  https://github.com/Seeed-Projects/reBot-DevArm.git (fetch)
upstream  https://github.com/Seeed-Projects/reBot-DevArm.git (push)
```

**理解**：
- `origin` = 你的 Fork（你有写权限，可以 push）
- `upstream` = 官方仓库（只读，用来同步更新）

---

## 第三步：配置 Git 用户信息（首次使用）

Git 需要知道你是谁，才能记录提交者信息：

```bash
git config --global user.name "你的GitHub用户名"
git config --global user.email "你的邮箱"
```

例如：
```bash
git config --global user.name "fanhao375"
git config --global user.email "fanhao375@gmail.com"
```

**注意**：邮箱要和 GitHub 账号绑定的邮箱一致，或者使用 GitHub 提供的隐私邮箱：
```
你的用户名@users.noreply.github.com
```

---

## 第四步：提交你的修改

### 4.1 查看当前状态

```bash
git status
```

会显示哪些文件被修改了、哪些是新文件。

### 4.2 添加文件到暂存区

```bash
# 添加所有修改
git add .

# 或者只添加特定文件
git add PROJECT_NOTE.md CHANGELOG.md
```

### 4.3 提交到本地仓库

```bash
git commit -m "添加学习笔记和补充资料"
```

**提交信息建议**：
- 第一行简短说明（50 字以内）
- 空一行
- 详细说明（可选）

例如：
```bash
git commit -m "添加学习笔记和补充资料

- 新增项目文档体系（PROJECT_NOTE/CHANGELOG/LEARNING_LOG）
- 补充硬件资料（电机说明书、硬件总结）
- 新增完整文档中心（docs/）
- 抓取并修复 8 个 wiki 教程页面

本仓库 Fork 自 Seeed-Projects/reBot-DevArm
标注 ★ 的内容为个人学习补充，非官方资料"
```

---

## 第五步：推送到 GitHub

### 5.1 首次推送

```bash
git push -u origin main
```

`-u` 参数会设置上游分支，以后只需要 `git push` 就行。

### 5.2 如果推送被拒绝

可能是因为远程仓库有你本地没有的提交（比如你 Fork 后官方又更新了）。

解决方法：
```bash
# 拉取远程更新并变基
git pull origin main --rebase

# 再次推送
git push
```

### 5.3 推送成功

访问你的 GitHub 仓库，刷新页面，应该能看到你的提交了。

---

## 第六步：同步官方仓库的更新

官方仓库会不断更新，你需要定期同步到你的 Fork。

### 6.1 拉取官方更新

```bash
git pull upstream main
```

这会把官方 `main` 分支的最新提交合并到你的本地。

### 6.2 推送到你的 Fork

```bash
git push origin main
```

这样你的 GitHub Fork 也同步了官方的最新内容。

### 6.3 完整流程（推荐）

```bash
# 1. 确保在 main 分支
git checkout main

# 2. 拉取官方更新
git pull upstream main

# 3. 推送到你的 Fork
git push origin main
```

---

## 常见问题

### Q1: 我改了文件，但 `git status` 显示很多不相关的修改？

可能是换行符问题（Windows 用 CRLF，Linux/Mac 用 LF）。

解决方法：
```bash
# 让 Git 自动处理换行符
git config --global core.autocrlf true
```

### Q2: 提示 "embedded git repository"？

你添加的文件夹里有 `.git` 子目录（嵌套仓库）。

两种处理方式：
1. **作为子模块**（推荐，如果是外部项目）：
   ```bash
   git rm --cached software/MotorBridge
   git submodule add https://github.com/tianrking/MotorBridge software/MotorBridge
   ```

2. **直接包含代码**（如果你要修改它）：
   ```bash
   rm -rf software/MotorBridge/.git
   git add software/MotorBridge
   ```

### Q3: 推送时要求输入用户名密码？

GitHub 已经不支持密码登录了，需要用 Personal Access Token (PAT)。

**方法 1：使用 SSH（推荐）**
```bash
# 生成 SSH 密钥
ssh-keygen -t ed25519 -C "你的邮箱"

# 添加到 GitHub：Settings → SSH and GPG keys → New SSH key
# 然后改用 SSH URL
git remote set-url origin git@github.com:你的用户名/reBot-DevArm.git
```

**方法 2：使用 Personal Access Token**
1. GitHub → Settings → Developer settings → Personal access tokens → Generate new token
2. 勾选 `repo` 权限
3. 复制生成的 token
4. 推送时用 token 代替密码

### Q4: 如何撤销还没 push 的提交？

```bash
# 撤销最后一次提交，但保留修改
git reset --soft HEAD~1

# 撤销最后一次提交，丢弃修改
git reset --hard HEAD~1
```

### Q5: 我想删除 Fork，重新来？

GitHub 仓库页面 → Settings → 拉到最底部 → Delete this repository

---

## 开源协议注意事项

本项目使用 **CC BY-NC-SA 4.0** 协议，你需要遵守：

| 要求 | 说明 |
|---|---|
| **Attribution（署名）** | 必须标明原作者和来源 |
| **NonCommercial（非商用）** | 不能用于商业目的 |
| **ShareAlike（相同方式共享）** | 你的衍生作品也必须用相同协议 |

**Fork 自动满足这些要求**：
- GitHub 会显示 "forked from 官方仓库"（署名）
- 协议文件 `LICENSE` 会自动继承（相同方式共享）
- 只要你不卖这个项目，就符合非商用

---

## 推荐工作流程

### 日常开发

```bash
# 1. 修改文件
# 2. 查看修改
git status
git diff

# 3. 提交
git add .
git commit -m "更新说明"

# 4. 推送
git push
```

### 定期同步官方

```bash
# 每周或每次开始工作前
git pull upstream main
git push origin main
```

### 分支开发（进阶）

如果你想尝试大改动，但不想影响主分支：

```bash
# 创建新分支
git checkout -b feature-new-docs

# 修改、提交
git add .
git commit -m "实验性文档"

# 推送到你的 Fork
git push -u origin feature-new-docs

# 如果满意，合并回 main
git checkout main
git merge feature-new-docs
git push
```

---

## 学习资源

- **Git 官方教程**：https://git-scm.com/book/zh/v2
- **GitHub 官方文档**：https://docs.github.com/zh
- **交互式 Git 教程**：https://learngitbranching.js.org/?locale=zh_CN
- **Git 速查表**：https://training.github.com/downloads/zh_CN/github-git-cheat-sheet/

---

## 本文档的由来

这份指南是在 2026-04-14 实际 Fork reBot-DevArm 项目时，根据真实操作过程整理而成。

目标是让零基础的人也能：
1. Fork 一个开源项目
2. 添加自己的学习笔记
3. 推送到 GitHub 分享给别人
4. 保持与官方同步

如果你在操作过程中遇到问题，欢迎提 Issue 或 PR 改进这份文档。

---

**记住**：Git 一开始可能有点难，但掌握这几个命令后，你就能自由地参与开源项目了。加油！🚀

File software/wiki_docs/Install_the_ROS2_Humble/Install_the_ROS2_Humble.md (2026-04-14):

# Install the ROS2 Humble

> 发布时间: 2025-05-28T00:00:00.000Z
> 原文链接: https://wiki.seeedstudio.com/install_ros2_humble/

---
On this page

ROS 2 is a next-generation open-source robotics middleware designed for building real-time, reliable, and scalable robotic systems. This wiki will demonstrate the detailed installation process of ROS 2 using Jetson as an example.

-   JP5.1.2
-   JP6.2

## Set Locale[](#set-locale "Direct link to Set Locale")

```
locale  sudo apt update && sudo apt install localessudo locale-gen en_US en_US.UTF-8sudo update-locale LC_ALL=en_US.UTF-8 LANG=en_US.UTF-8export LANG=en_US.UTF-8locale
```

## Install Dependencies[](#install-dependencies "Direct link to Install Dependencies")

```
sudo apt update && sudo apt install gnupg wgetsudo apt install software-properties-commonsudo add-apt-repository universe
```

## Initialize Sources (Choose One Region)[](#initialize-sources-choose-one-region "Direct link to Initialize Sources (Choose One Region)")

```
echo 'deb https://isaac.download.nvidia.com/isaac-ros/ubuntu/main focal main' | sudo tee -a /etc/apt/sources.listecho 'deb https://isaac.download.nvidia.cn/isaac-ros/ubuntu/main focal main' | sudo tee -a /etc/apt/sources.list
```

## Add ROS 2 APT Repository[](#add-ros-2-apt-repository "Direct link to Add ROS 2 APT Repository")

```
sudo apt update && sudo apt install curl -y \&& sudo curl -sSL https://raw.githubusercontent.com/ros/rosdistro/master/ros.key -o /usr/share/keyrings/ros-archive-keyring.gpgecho "deb [arch=$(dpkg --print-architecture) signed-by=/usr/share/keyrings/ros-archive-keyring.gpg] http://packages.ros.org/ros2/ubuntu focal main" | sudo tee /etc/apt/sources.list.d/ros2.list > /dev/null
```

## Install ROS2[](#install-ros2 "Direct link to Install ROS2")

```
sudo apt updatesudo apt install ros-humble-desktop-full
```

## Install Additional Build Tools[](#install-additional-build-tools "Direct link to Install Additional Build Tools")

```
sudo apt install ros-dev-tools
```

## Initialize ROS Environment[](#initialize-ros-environment "Direct link to Initialize ROS Environment")

```
sudo rosdep initrosdep update
```

## Set Up ROS Environment Variables[](#set-up-ros-environment-variables "Direct link to Set Up ROS Environment Variables")

```
echo "source /opt/ros/humble/setup.bash" >> ~/.bashrcsource ~/.bashrc
```

On the Jetson device, open a terminal and enter the following command:

```
sudo apt install software-properties-common -ysudo add-apt-repository universesudo apt updatesudo apt install curl -ysudo curl -sSL https://raw.githubusercontent.com/ros/rosdistro/master/ros.key -o /usr/share/keyrings/ros-archive-keyring.gpgecho "deb [arch=$(dpkg --print-architecture) signed-by=/usr/share/keyrings/ros-archive-keyring.gpg] http://packages.ros.org/ros2/ubuntu $(. /etc/os-release && echo $UBUNTU_CODENAME) main" | sudo tee /etc/apt/sources.list.d/ros2.list > /dev/nullsudo apt updatesudo apt install ros-humble-desktop -y
```

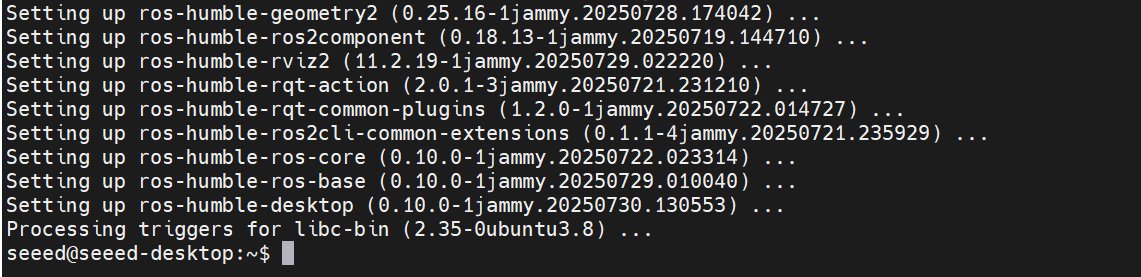
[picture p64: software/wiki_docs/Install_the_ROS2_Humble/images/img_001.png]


To verify whether ROS2 has been successfully installed, we can create two new terminals in the device and run the following commands respectively.

```
ros2 run demo_nodes_cpp talkerros2 run demo_nodes_py listener
```

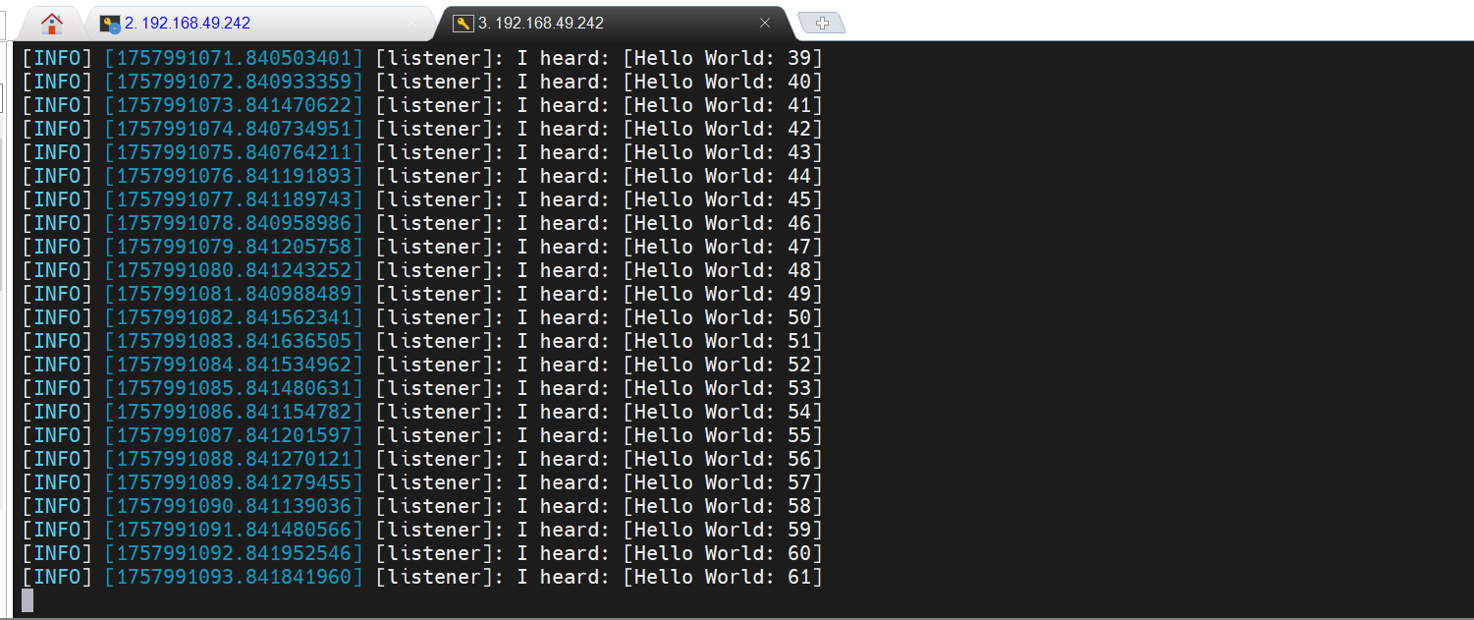
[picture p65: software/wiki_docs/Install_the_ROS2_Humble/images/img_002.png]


If both terminals print out the messages, it means ROS 2 Humble has been successfully installed! 🎉

## Tech Support & Product Discussion[](#tech-support--product-discussion "Direct link to Tech Support & Product Discussion")

Thank you for choosing our products! We are here to provide you with different support to ensure that your experience with our products is as smooth as possible. We offer several communication channels to cater to different preferences and needs.

[](https://forum.seeedstudio.com/)[](https://www.seeedstudio.com/contacts)

[](https://discord.gg/eWkprNDMU7)[](https://github.com/Seeed-Studio/wiki-documents/discussions/69)

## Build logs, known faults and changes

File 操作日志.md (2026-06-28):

# 更新日志

记录本仓库的所有本地修改和操作，方便后续 AI 或协作者理解上下文。

---

## 2026-05-28

### 2026-05-29 本地实操：重力补偿双版本 + LeRobot follower 验证通过

**触发**：用户完成带锁/不带锁重力补偿实操，并进入 LeRobot follower 键盘控制验证；5-29 询问“项目地址或上游有更新，应该同步一下，再同步咱们的进度是不是”。

**先同步上游**：

- 本地 `git fetch --all --prune` 后发现 `origin/main` 从 `f6bb354` 更新到 `fa2f626`，新增 tag `baseline-2026-05-28`。
- 执行 `git merge --ff-only origin/main`，主仓快进到 2026-05-28 基线。
- 执行 `git submodule update --init software/MotorBridge`，`software/MotorBridge` 更新到 `23c2299`。
- 保留本地未跟踪文档和工具，不覆盖用户/本地改动。

**当前重要区分**：

| 项 | 状态 |
|---|---|
| 主仓源码基线 | `baseline-2026-05-28` |
| `software/MotorBridge` submodule | `23c2299`，对应 MotorBridge v0.3.9 |
| WSL 重力补偿 Python 环境 | `motorbridge 0.3.7`，Pinocchio `3.9.0` |
| LeRobot conda 环境 | `lerobot 0.5.2` / `motorbridge 0.3.7` / `lerobot_robot_seeed_b601 0.1.2` |

**真机验证结果**：

| 项 | 结果 |
|---|---|
| 达妙 USB-CAN 串口 | WSL `/dev/ttyACM0` |
| 总线扫描 | 扫到 7 个电机 `0x01..0x07`，反馈 ID `0x11..0x17` |
| 无锁重力补偿 | `example/9_gravity_compensation.py` 短跑通过：连接 OK、使能 OK、MIT 模式 OK、500Hz 控制环、`tau_g` 输出正常 |
| 带锁重力补偿 | `example/10_gravity_compensation_lock.py` 短跑通过：初始目标角度锁定、MIT 模式 OK、`LOCKED` 状态正常 |
| LeRobot follower 校准 | `lerobot-calibrate --robot.type=seeed_b601_dm_follower --robot.port=/dev/ttyACM0 --robot.id=follower1 --robot.can_adapter=damiao` 完成 |
| 校准文件 | `/home/pc/.cache/huggingface/lerobot/calibration/robots/seeed_b601_dm_follower/follower1.json` |
| 校准后只读位置 | 7 个关节读数都在 `0 deg` 附近 |

**键盘控制结论**：

- 官方 LeRobot `--teleop.type=keyboard` 不是给 B601 这种 7 关节 follower 直接做关节 jog 的，action 字段不匹配。
- 本仓新增本地安全小步进脚本：`tools/lerobot_b601_keyboard_jog.py`。
- 默认每按一次移动 `1 deg`，并带 `max_relative_target=2 deg` 保护。
- 推荐第一次只按 `s` 读位置，再试 `6/y` wrist_roll，退出按 `x`。

**文档同步**：

- 更新 `LeRobot_follower验证小白执行手册.md`：增加 2026-05-29 当前进度、验收清单改为已通过、补键盘 jog 路径。
- 更新 `重力补偿小白执行手册.md`：增加无锁/带锁两种验证结果和运行命令。
- 更新 `遥操作与LeRobot待办.md`：阶段 1 单臂基础验证、阶段 2 LeRobot follower 验证改为已完成；当前决策点改为 leader 选型。
- 更新 `项目总览.md`：顶部最后本地进展和更新记录同步到 2026-05-29。

**下一步**：

1. 决策 leader 路线：SO-101 起步，还是 reBot 102 leader。
2. 如果继续 LeRobot，进入 leader 采购/打印/安装/校准。
3. 摄像头和数据采集放在 leader 决策之后。

---

### 上游同步：MotorBridge v0.3.7 → v0.3.9 + 主仓 GEM-4/UVC32/电源 + Python wheel 升 0.3.9

**触发**：5-27 用户问上游，5-27 spawn subagent 复核（达妙零改动 / API 100% 兼容 / 主仓 4 commit 文档资源类），用户 5-28 拍板执行。

**上游变化**：

| 仓 | 新增 commit | 性质 |
|---|---|---|
| 主仓 | 4 | GEM-4 社区视频链接 + UVC32 摄像头支架 STEP + 电源 BOM 文档完善 |
| `MotorBridge` | 2（`a6c14d7 → 23c2299`）| v0.3.8 + v0.3.9 release，全 RobStride / Windows PCAN 增强；达妙路径零改动 |
| 其他 3 仓 | 0 | — |

**重要纠正**：GEM-4 不是 reBot 官方推 Gemma 模型集成，是别人用 Google Gemma 控 reBot Arm 做的 demo 视频，上游加进了 README "Feedback from the community" 表格。性质等同"用户晒图"。

**对项目影响**：
- 达妙路径：完全零改动（实测确认）
- Python API：100% 兼容
- WebSocket scan 协议：向后兼容
- UVC32 摄像头支架：未来"装摄像头"阶段可考虑（详见 `遥操作与LeRobot待办.md §4 平行支线 1`）

**操作**：

| 步骤 | 内容 | 结果 |
|---|---|---|
| 1 | fork MotorBridge fast-forward + push | `a6c14d7..23c2299` |
| 2 | 主仓建 `sync/upstream-2026-05-28` 分支 + commit submodule 指针 | sync commit `e150c82` |
| 3 | 合 sync → main | `50fb1ca` |
| 4 | 主仓 merge upstream/main（4 commit）| `50af470` |
| 5 | Python wheel 0.3.7 → 0.3.9 双端 | ✅ Win + WSL |
| 6 | 打 `baseline-2026-05-28` tag | ✅ |

**详情**：`上游更新记录/2026-05-28_同步详情.md`

---

## 2026-05-25

### 上游同步：MotorBridge v0.3.5 → v0.3.7 + Python wheel 升 0.3.7

**触发**：用户主动询问上游。

**按 memory 规则 spawn subagent 复核**——这次跟初判一致，subagent 实测确认：达妙路径真零改动，scan 改动独立子命令不影响 follower。

**上游变化**：

| 仓 | 新增 commit | 性质 |
|---|---|---|
| `MotorBridge` | 2（`96dddf3 → a6c14d7`）| v0.3.6 + v0.3.7 release：全是 RobStride / Windows PCAN / ws_gateway 增强；达妙路径 0 行改动 |
| 其他 4 仓 | 0 | reBotArm_control_py 在 upstream/main 有 `8427281 add pip` 但 develop 没动，我们追 develop |

**v0.3.6 / v0.3.7 要点**：
- Fixed: Windows PCAN RobStride 多 controller 抢通道 / 扫描误报 / 单 host 扫描实时打印 / Windows 时序 clamp
- Added: MOTORBRIDGE_WS_DEBUG / capabilities op / batch_scan op / scan_progress 流式事件 / PCAN 错误码名称映射
- Python scan 回归测试（test_scan.py）

**对项目影响**：
- 达妙路径：完全零改动（实测 `git diff --stat motor_vendors/damiao/` 空输出）
- Python API：100% 兼容（Controller / Motor / Mode / send_mit / ensure_mode 等签名未变）
- WebSocket `{"op":"scan"}` JSON 协议：向后兼容（旧字段未改）
- `lerobot-robot-seeed-b601` follower 适配器：零调用 scan，无影响

**操作**：

| 步骤 | 内容 | 结果 |
|---|---|---|
| 1 | fork MotorBridge fast-forward + push | `96dddf3..a6c14d7` |
| 2 | 主仓建 `sync/upstream-2026-05-25` 分支 + commit submodule 指针 | sync commit `c8957b6` |
| 3 | 合 sync → main | `556aca1` |
| 4 | Python wheel 0.3.5 → 0.3.7 双端 | ✅ Win + WSL |
| 5 | 打 `baseline-2026-05-25` tag | ✅ |

**详情**：`上游更新记录/2026-05-25_同步详情.md`

---

## 2026-05-21

### 上游同步：MotorBridge v0.3.2 → v0.3.5 + 主仓 OSHW 认证 + Python wheel 升 0.3.5

**触发**：用户主动询问上游。

**按 memory 规则 spawn subagent 复核**——抓到 1 个我的初判错误：`96dddf3 feat: support damiao observation parameter stream` commit message 让我误判为"motor 层达妙改动"，实际是 ws_gateway 层。

**上游变化**：

| 仓 | 新增 commit | 性质 |
|---|---|---|
| 主仓 | 1（`d6ed5f3`）| OSHW 认证标识 + 社区反馈图（无功能影响）|
| `MotorBridge` | 8（`bcfc3c1 → 96dddf3`）| v0.3.5 release：达妙路径 3 文件 bugfix（API 100% 兼容）+ RobStride 流式订阅 + ws_gateway 加达妙 WS 流 + Drop impl 自动清线程 + 新 `__version__` |
| 其他 3 仓 | 0 | — |

**对项目影响**：
- 达妙路径：`ensure_mode()` 行为增强（内置 3 次重试），`open_socketcan→open_can_bus` 跨平台后端选择器（旧名保留），ABI 内部 Rust 重构（FFI 无感）
- Python API 全部签名未变；新增 `motorbridge.__version__` 等
- `lerobot-robot-seeed-b601` follower 适配器**完全兼容**且有利好（Drop polling 清理 / ensure_mode 内置重试）

**操作**：

| 步骤 | 内容 | 结果 |
|---|---|---|
| 1 | fork MotorBridge fast-forward + push | `bcfc3c1..96dddf3` |
| 2 | 主仓建 `sync/upstream-2026-05-21` 分支 + commit submodule 指针 | sync commit `6f5ffc5` |
| 3 | 合 sync → main | `4f1c2b2` |
| 4 | 主仓 merge upstream/main（OSHW README）| `dced175` |
| 5 | Python wheel 0.3.2 → 0.3.5 双端 | ✅ Win + WSL |
| 6 | 打 `baseline-2026-05-21` tag | ✅ |

**详情**：`上游更新记录/2026-05-21_同步详情.md`

---

## 2026-05-18

### 上游同步：MotorBridge v0.3.2 + ROS2 仓 launch 重命名 + Python wheel 升 0.3.2

**触发**：用户主动询问上游更新。

**按 memory 规则 spawn subagent 复核**——抓到我 2 个初判错误（MotorBridge commit 数 5 → 实际 9；ROS2 仓 4 commit 误判为"漏合"实际是真新）。

**上游变化**：

| 仓 | 新增 commit | 性质 |
|---|---|---|
| `MotorBridge` | 9（`681f021 → bcfc3c1`） | v0.2.9 + v0.3.0/0.3.1/0.3.2 + RobStride 协议规范化 + Python CLI 修复 + slcan→canable 脚本重命名（达妙路径基本零改动）|
| `reBotArmController_ROS2` | 4（`92ceb76 → 682d12f`） | ⚠️ **破坏性**：driver_only→driver.launch.py 重命名 / rviz.launch.py 删 / safe_home() 不再自动闭夹爪 + 新增 `GripperCommand.srv`（+853/-241 行 29 文件）|
| `reBotArm_control_py` upstream/develop | 0 | 不动 |
| 主仓 + StarArm_102 | 0 | — |

**对项目影响**：
- 达妙路径：Python wheel 升 0.3.2，**业务零影响**（subagent 实测 `motor_vendors/damiao/` 只有 1 行 typo 级改动）
- ROS2 仓破坏性变更：当前装机阶段没消费这些 launch/msg，**零影响**；等真要跑 ROS2 时按新接口写
- 装机烧录指南脚本路径没引用 slcan_restart.sh，**零影响**

**操作（走 sync 分支）**：

| 步骤 | 内容 | 结果 |
|---|---|---|
| 1 | fork MotorBridge fast-forward + push | `681f021..bcfc3c1` |
| 2 | fork reBotArmController_ROS2 fast-forward + push | `92ceb76..682d12f` |
| 3 | 主仓建 `sync/upstream-2026-05-18` 分支并 commit 双 submodule 指针 | sync commit `0a19218` |
| 4 | 合 sync → main | `23d5a48` |
| 5 | Python wheel 0.2.8 → 0.3.2 双端 | ✅ Win + WSL |
| 6 | 打 `baseline-2026-05-18` tag | ✅ |

**详情**：`上游更新记录/2026-05-18_同步详情.md`

---

## 2026-05-15

### 装机阶段全通关：电机 ID + 零点 + 整机控制全部跑通

**用户实操进展**（用户原话："我电机 reBot Arm B601-DM 已经都配置好了，用那个 MotorBridge 的网页也可以移动测试啥的"）：

| 项 | 状态 |
|---|---|
| 7 个电机 motor_id 烧录（0x01..0x07） | ✅ 全完 |
| 7 个关节零点标定（set_zero_position） | ✅ 全完 |
| 机械臂结构件物理拼装 | ✅ 整机成型 |
| MotorBridge Web UI 整机控制 | ✅ 同时控 7 个电机能动 |
| 24V 电源对地短路检查 | ✅ |
| CAN-H/L 60Ω 终端电阻测试 | 跳过（Web UI 整机通信 OK 反推 CAN 正常） |
| 单电机命令行测试 | 跳过（Web UI 已覆盖等价功能） |

**意义**：装机烧录指南 §1-§5（焊线→拼装→上电→烧 ID→标零点）全部走完，进入 §6 跑代码阶段。

### LeRobot 集成评估：clone Seeed-Projects/lerobot-robot-seeed-b601 等 3 仓 + SO-ARM100 入探索区

**触发**：5-14 找到 Seeed 官方 wiki 提到的 LeRobot 集成方案（含为达妙 reBot Arm B601-DM 写的 follower 适配器）。今日 clone 4 个相关仓到 `_lerobot_experiment/`（gitignored）评估区：

- `huggingface/lerobot`（主线，含 `so_leader` 一等公民支持 SO-100/SO-101）
- `Seeed-Projects/lerobot-robot-seeed-b601`（reBot Arm follower 适配器，确认 import motorbridge 调达妙 CAN）
- `Seeed-Projects/lerobot-teleoperator-rebot-arm-102`（reBot 102 leader 适配器）
- `TheRobotStudio/SO-ARM100`（SO-100/SO-101 硬件仓，含完整 STEP/STL + Seeed 配套安装板设计）

**关键发现**：
- `reBotArm_control_py` 完全没多臂/teleop 代码（grep 0 匹配）—— 多臂逻辑完全在 LeRobot 框架层
- follower 适配器代码里有 `if 'wrist_yaw' not in goal_pos: goal_pos['wrist_yaw'] = 0.0` —— **作者已经为"6 DOF leader 控 7 关节 follower"做了兼容**，意味着 SO-101 leader 控 reBot Arm follower 在代码层已设计支持
- SO-ARM100 仓内有 `Seeedstudio_Mounting_Plate_SO101.step` —— **Seeed 自己提供 SO-101 → reBot Arm 安装板设计**，认可混搭

**未升级到 submodule**：3 个 Seeed 仓 + huggingface/lerobot 都保留在探索区，按"评估通过再 fork + submodule"原则，等阶段 2 LeRobot follower 实操跑通再决定。

详见 `_lerobot_experiment/README.md` + `遥操作与LeRobot待办.md`。

### 装机烧录指南 §6.4 重力补偿：完整 cookbook（WSL 主路径）

**目标**：把"跑重力补偿"从指南骨架里 4 行扩展成完整可执行 cookbook。

**Windows 路径尝试失败**：`pip install pin` 在 Python 3.12 Windows 上**没 wheel**，pip 退回**源码编译**（cmeel-boost + libpinocchio + scipy 等，需 MSVC/Boost/cmake 全套），30 分钟没编出来，已 kill。原因：Pinocchio 在 Windows 主要靠 conda-forge 分发 binary，PyPI 没有 Python 3.12 Windows wheel。

**切到 WSL 主路径**：
- WSL2 Ubuntu Python 3.10 + Pinocchio 3.9.0 已确认装好（之前装的）
- 跟 reBotArm_control_py README 官方推荐 "Operating System: Ubuntu 22.04+" 一致
- 唯一额外配置：Windows 装 `usbipd-win` 把 USB-CAN 设备转发给 WSL

§6.4 新内容（约 150 行）：
- 前置条件 7 项检查清单
- 一次性准备（usbipd-win 安装）
- 实操 8 步（接 USB → bind → attach → WSL chmod → 跑脚本 → 看输出 → 真机验证 → 安全停止）
- 预期终端输出完整示例
- 9 条常见报错排查表
- Windows 失败附录 + conda-forge 备选提示

**待用户实操**：硬件已搭好（电机配置完成），照 §6.4 一步步走即可。

### Memory 更新

- 新建 `feedback_subagent_review_routine.md`：评估/建议/决策类任务都先 spawn subagent 复核（不只上游同步）
- 新建 `project_teleop_leader_choice_risk.md`：reBot 102 vs SO-ARM101 leader 选型风险记录
- 5-15 更新：用户确认**102 和 SO-101 都没买**，决定哪个就 3D 打印；leader 选型变成"完整新装决策"

### 文档同步

- `装机烧录指南.md` §6.4 重写为 WSL 主路径
- `遥操作与LeRobot待办.md` 现状段更新（leader 全空白 + 文档校准声明）
- `操作日志.md` 追加本条
- `项目总览.md` 最后同步时间 + 记录表加 2026.05.15
- `复刻基线维护原则.md` 最后更新日期 → 2026-05-15

---

## 2026-05-14

### 上游同步：MotorBridge 681f021 + ROS2 仓 MoveIt 2 集成 + 主仓 README

> 📌 **日期校准声明**：本条目最初按错误的系统日期记录为"2026-05-13 第二批，傍晚"，5-14 当天发现后修正。tag `baseline-2026-05-13-2` 已重命名为 `baseline-2026-05-14`；上游更新记录文件 `2026-05-13b_同步详情.md` → `2026-05-14_同步详情.md`。git merge commit message 内的 `sync/upstream-2026-05-13b` 字样保留，不重写历史。

**触发**：用户询问上游，发现 4 个仓里有 3 个有更新（主仓 1 + MotorBridge 2 + ROS2 仓 2 + reBotArm_control_py 上游 main 3 但 develop 0）。用户明确"按持续追新原则同步，文档记录变动即可"。

**上游变化**：

| 仓库 | 新增 commit | 性质 |
|---|---|---|
| `Seeed-Projects/reBot-DevArm` | 1（`53f5d5f`） | README_zh ROS2 wiki 链接更新 |
| `motorbridge/motorbridge` | 2（`681f021` + dependabot） | PCAN 重启文档 + rand 依赖升级 |
| `EclipseaHime017/reBotArmController_ROS2` | 2（`92ceb76` + `802f3c3`） | ⭐ **MoveIt 2 集成 + 柔性夹爪新 URDF**（+4607/-847 行 62 文件） |
| `vectorBH6/reBotArm_control_py` upstream/main | 3 | 删 `1_damiao_text.py` + 5 个 README + IK 测试 |
| `vectorBH6/reBotArm_control_py` upstream/develop | 0 | 无改动 |

**⚠️ reBotArm_control_py 特殊状况**：上游 main 跟 develop 已分叉，今天的 3 个破坏性改动（含删 `1_damiao_text.py`）只在 main，develop 未变。我们 5-08 同步时确立追 develop 分支，所以**本仓今天不同步该 submodule**，等上游把 main 合回 develop 或明确主线方向再处理。`1_damiao_text.py` 在本仓继续可用。

**ROS2 仓 MoveIt 2 集成关键内容**：
- 新增 `rebotarm_moveit_demos` 包：`demo_common.py` / `draw_square.py` / `pick_place.py`
- 消息接口拆分：旧 `JointMotorCmd.msg`（20 字段）→ 新 `JointMitCmd` + `JointPosVelCmd` + `JointVelCmd`（破坏性 ABI 变更，但本仓还没消费这些 msg）
- `hardware_manager.py` +/-708 行重写、`ros_actions.py` -184 行简化

**操作（走 sync 分支）**：

| 步骤 | 内容 | 结果 |
|---|---|---|
| 1 | fork MotorBridge fast-forward + push | `a2b50ed..681f021` |
| 2 | fork reBotArmController_ROS2 fast-forward + push | `d3a415e..92ceb76` |
| 3 | 主仓建 `sync/upstream-2026-05-13b` 分支并 commit 双 submodule 指针 | sync commit `bda8dd7` |
| 4 | 合 sync → main | `a86b8c2` |
| 5 | 主仓 merge upstream/main（README 1 行） | `5ccbcda` |
| 6 | 打 `baseline-2026-05-14` tag（最初误命名 `baseline-2026-05-13-2`，已校准） | ✅ |

**对项目影响**：
- 达妙路径：完全不受影响（MotorBridge 改的是 PCAN 文档 + 依赖）
- Python wheel：不需要再升级（0.2.8 → 0.2.8，今日 2 个 commit 还没发新版）
- ROS2 stack：本仓目前没消费 msg，破坏性变更对本仓零影响；等真要跑 MoveIt 2 演示时按新 msg 接口写代码

**详情**：`上游更新记录/2026-05-14_同步详情.md`

---

## 2026-05-13

### 装机烧录指南：追加 §12 待决项（视频太长无章节标记）

**触发**：用户实操跟读 B 站官方装机视频 BV1K9dbBNEdC 时反馈"一个小时纯机械+穿线，想跳到具体步骤跳不到，挺难受的"。

**改动**：`装机烧录指南.md` 新增 §12.1 待决项，列 3 个候选方案（A. 章节时间戳地图 / B. 重剪视频 / C. 文字+实拍图笔记），优先级未定，等装第二台或做小红书时再判断。

**commit**：`7bde0fd 装机烧录指南：追加 §12 待决项`

### 上游同步：主仓 LICENSE 协议大更新 + MotorBridge 升级 v0.2.6 → v0.2.8

**触发**：用户连续多日询问上游更新状态，今日确认 MotorBridge 0.2.8 发版后授权同步（"那也更新加上吧"）。

**上游变化**：

| 仓库 | 新增 commit | 性质 |
|---|---|---|
| `Seeed-Projects/reBot-DevArm` | 2（`b738018` + `ae5f123`） | LICENSE 协议大改 + STEP 文件修复 |
| `motorbridge/motorbridge` | 9（`faba15f..a2b50ed`） | 全部 RobStride 路径，达妙零改动 |

**主仓 LICENSE 重构**：从单一 CC BY-NC-SA 4.0（禁商用）拆成"硬件 CERN-OHL-W 2.0 + 软件 Apache 2.0"双协议（允许商业使用）。5 个语言版本 README 同步更新协议徽章。

**MotorBridge 0.2.6 → 0.2.8**：RobStride 型号专属参数表、零点范围、运行时参数补全，跟达妙路径完全无关。

**对项目影响**：
- 达妙路径完全不受影响（`motor_vendors/damiao/` 一行未改，`bindings/python/` 仅版本号 0.2.6 → 0.2.8）
- 主仓 STEP 文件跟用户无关（用户买完整套装，不自己 3D 打印零件）
- 协议变更允许后续考虑公开版/商用衍生品

**操作**：

| 步骤 | 内容 | 结果 |
|---|---|---|
| 1 | fork MotorBridge 内 `git merge --ff-only upstream/main` | submodule HEAD `b9f7065` → `a2b50ed` |
| 2 | `git push origin main`（fanhao375/motorbridge） | `b9f7065..a2b50ed` 已推送 |
| 3 | 主仓 `sync/motorbridge-2026-05-13` 分支 commit submodule 指针 | sync commit `12df10f` |
| 4 | 静态验证：`motor_vendors/damiao/` 零改动 / Python binding 仅版本号变 | ✅ |
| 5 | 合 sync → main | `d6ef5be` |
| 6 | 主仓 `git merge upstream/main` 引入 LICENSE + STEP | `02ba6eb` |
| 7 | Python wheel 双端 0.2.6 → 0.2.8 | ✅ Windows + WSL2 |

**详情**：`上游更新记录/2026-05-13_同步详情.md`

---

## 2026-05-09

### 上游同步：MotorBridge 升级到 b9f7065（v0.2.4 → v0.2.6）

**触发**：检查上游发现 motorbridge 新发 v0.2.5 + v0.2.6 双版本，用户授权同步。

**上游变化**（`motorbridge/motorbridge:main` 新增 3 个 commit）：
- `21c12d7` Release Python package 0.2.5（CLI 增强 + 文档更新）
- `a258ec5` fix(robstride): align scan and id handling for 0.2.6（⭐ RobStride 底层重写 + Python 绑定新增 host_id 变体方法 + ID 范围校验 + 删除 mintlify 文档目录改放 docs/）
- `b9f7065` docs（CAN 排障链接）

**对项目影响**：
- 达妙路径完全不受影响（add_damiao_motor / Mode / Controller 没动）
- reBotArm_control_py 配置全部 `vendor: damiao`，不走改动的 RobStride 分支
- 即便将来切 RobStride，本仓 motor_id 0x01..0x07、feedback_id 0x11..0x17 都在新版校验范围内
- Python 环境侧：Windows Python 3.12 当前是 wheel 0.2.4，submodule 升级不自动同步到环境，需 Rust 工具链 cargo build + pip install -e --force-reinstall

**操作（按复刻基线维护原则规则 5 走 sync 分支）**：

| 步骤 | 内容 | 结果 |
|---|---|---|
| 1 | fork 内 `git merge --ff-only upstream/main`（无本地分歧，fast-forward） | submodule HEAD `f7037b0` → `b9f7065` |
| 2 | `git push origin main`（fanhao375/motorbridge） | `f7037b0..b9f7065` 已推送 |
| 3 | 主仓新建 `sync/motorbridge-2026-05-09` 分支并 commit submodule 指针 | sync commit `a581732` |
| 4 | 静态验证 + 隔离性验证 | ✅ AST 全过、改动 100% 隔离在 RobStride 路径、达妙 API 未动 |
| 5 | 合入 main + 打 baseline tag | ✅ `baseline-2026-05-09` 已打并 push |
| 6 | Python 环境升级 wheel 到 0.2.6 | ✅ Windows Python 3.12 + WSL2 Ubuntu Python 3.10 双端从 PyPI 直接装预编译 wheel（不需要 Rust 工具链）；新符号 `motor_handle_robstride_ping_host_id` / `motor_handle_robstride_get_param_f32_host_id` 已在 .dll/.so 解析；`Motor.robstride_ping_host_id` / `robstride_get_param_f32_host_id` 方法可见；`add_robstride_motor` 1..255 范围校验生效 |

**关键发现**：上游 motorbridge 已发布 PyPI wheel（0.2.6 / 0.2.5 / 0.2.4 ...），不必本地 cargo build，`pip install --upgrade motorbridge` 直接拉预编译版本。

**详情**：`上游更新记录/2026-05-09_同步详情.md`

---

## 2026-05-08

### 上游同步：reBotArm_control_py 升级到 062bef9（含 RobotArm.fresh()）

**触发**：用户明确要求升级 `reBotArm_control_py`（`2026-05-06_同步详情.md` 写明此触发条件）。

**上游变化**（`vectorBH6/reBotArm_control_py:develop` 新增 1 个 commit `5537201 fix G`）：
- 新增 `RobotArm.fresh()` 空指令方法（不切换模式，把控制量清零）
- `example/9_gravity_compensation.py`：`mode_mit()` 后调用 `arm.fresh()`
- `example/10_gravity_compensation_lock.py`：`_KP 8.0→7.0`、`_KD 1.0→0.8`，并加 `arm.fresh()`
- 上游噪声：误提交 `__pycache__/arm.cpython-310.pyc`（fork 已 .gitignore，合并时保持删除）

**操作（按复刻基线维护原则规则 5 走 sync 分支）**：

| 步骤 | 内容 | 结果 |
|---|---|---|
| 1 | fork 内 `git merge --no-ff upstream/develop`，解决 pyc 冲突（保持删除） | submodule HEAD `5ae4d56` → `062bef9` |
| 2 | `git push origin develop`（fanhao375/reBotArm_control_py） | `5ae4d56..062bef9` 已推送 |
| 3 | 主仓新建 `sync/rebotarm-control-py-2026-05-08` 分支并 commit submodule 指针 | sync commit `dcca918` |
| 4 | 静态验证 | ✅ AST 全过、`fresh()` 方法存在、9/10 号示例已调用、KP/KD 参数到位 |
| 5 | 运行验证（fk_sim/ik_sim/traj_sim） | ⏳ 待 Python 3.10 + uv + Pinocchio 环境 |
| 6 | 合入 main + 打 baseline tag | ⏳ 等用户决策 |

**详情**：`上游更新记录/2026-05-08_同步详情.md`

---

## 2026-05-07

### 发现：官方 wiki 文档中的 ROS2 仓库地址问题

**背景**：检查官方 wiki 文档 [reBot Arm B601-DM ROS2 Integration](https://wiki.seeedstudio.com/rebot_arm_b601_dm_ros2_integration/)，发现文档中给出的仓库地址存在问题。

**官方文档中提到的地址**：
1. `https://github.com/Seeed-Projects/reBotArmController_ROS2.git` - 作为主要安装地址
2. `https://github.com/EclipseaHime017/reBotArmController_ROS2.git` - 作为"开发仓库"备选

**实际验证结果**：
- ❌ `Seeed-Projects/reBotArmController_ROS2` - **仓库不存在**（GitHub 返回 404）
- ✅ `EclipseaHime017/reBotArmController_ROS2` - 仓库存在且可用（3 commits, v0.0.2）

**当前配置**：
- 本地 submodule 已正确配置：
  - `origin`: `https://github.com/fanhao375/reBotArmController_ROS2.git` (个人 fork)
  - `upstream`: `https://github.com/EclipseaHime017/reBotArmController_ROS2.git` (实际可用的上游)

**结论**：
- 官方文档存在错误，`Seeed-Projects` 组织下的仓库尚未创建
- 目前唯一可用的上游是 `EclipseaHime017` 的个人开发仓库
- 本项目的 fork 和 upstream 配置是正确的

**后续观察**：
- 持续关注官方是否会创建 `Seeed-Projects/reBotArmController_ROS2` 正式仓库
- 如果官方创建正式仓库，届时可考虑切换 upstream 指向

---

## 2026-05-06

### 上游同步：ROS2 集成状态 + 独立 ROS2 submodule

**背景**：用户已 fork `fanhao375/reBotArmController_ROS2`，并询问 Seeed 官方 README 中的 ROS2 完成是否对应实际源码。检查后确认：主仓库只更新 README 状态和链接，ROS2 源码在独立工作区仓库里。

**同步结果**：

| 项目 | 结果 |
|---|---|
| `Seeed-Projects/reBot-DevArm` | 已合并 `a7d923b..511e140`，本地 merge commit `9fe4cf2` |
| `software/reBotArmController_ROS2` | 新增 submodule，指向 `fanhao375/reBotArmController_ROS2` 的 `d3a415e` |
| `Seeed-Projects/reBotArmController_ROS2` | Git / GitHub API 当前仍返回 404，暂不作为 upstream |
| `EclipseaHime017/reBotArmController_ROS2` | 当前可用上游，submodule 内已配置为 `upstream` |

**主要判断**：
- 官方主仓库本次只改 `README.md` / `README_zh.md`，没有新增 ROS2 包、launch、URDF、`package.xml` 等源码文件。
- ROS2 集成应按独立项目管理，放在 `software/reBotArmController_ROS2`，不复制进主仓库普通目录。
- `reBotArm_control_py` 的 `upstream/develop` 有 `5537201 fix G`，但属于功能性控制代码升级，本次不混入，后续按 submodule 升级流程单独验证。

**提交**：
- `6a41652` 接入 reBotArmController_ROS2 submodule
- `9fe4cf2` Merge remote-tracking branch 'upstream/main'

**文档更新**：
- `项目总览.md`
- `software/README_zh.md`
- `复刻基线维护原则.md`
- `Git操作指南.md`
- `上游更新记录/README.md`
- `上游更新记录/2026-05-06_同步详情.md`

**待验证**：
- ROS2 Humble 环境下 `colcon build`
- `rclpy` / `motorbridge` / `reBotArm_control_py` 同环境 import
- `bringup.launch.py` / `driver_only.launch.py` 启动验证
- 真机 ROS2 topic/service/action 调用验证

---

## 2026-05-05

### 上游同步：主仓库 + reBotArm_control_py

**背景**：检查上游发现两处更新，按"持续追上游最新进展"原则同步。

**同步结果**：

| 仓库 | 升级前 | 升级后 | 增量 |
|---|---|---|---|
| 主仓库 reBot-DevArm | c337d44 | a006965 | +1 commit |
| reBotArm_control_py | a5078ae | 5ae4d56 | +11 commit |

**主要变化**：
- **主仓库**：新增软体夹爪（Soft Gripper）的 3D 打印件 STEP 文件 + 5 个 README 多语言更新
- **reBotArm_control_py**：补齐 4 种语言 README（中/西/日/法）+ 新增 `example/1_damiao_text.py` 达妙电机示例 + 合并外部贡献者 PR ⭐

**操作流程**：
1. 主仓库：`git fetch upstream` + `git merge upstream/main`（fast-merge，1 个 commit）
2. reBotArm_control_py（在 fork 的 develop 分支上）：
   - `git checkout develop` + `git merge upstream/main`（无冲突，本地修复 a5078ae 保留）
   - `git push origin develop`（推到 fanhao375/reBotArm_control_py）
   - 回主仓库 `git add software/reBotArm_control_py` + commit

**提交**：
- `a006965` Merge remote-tracking branch 'upstream/main'（主仓库）
- `a00cb9d` 升级 reBotArm_control_py submodule: a5078ae → 5ae4d56

**详细记录**：[`上游更新记录/2026-05-05_同步详情.md`](上游更新记录/2026-05-05_同步详情.md)

**待验证**：
- 主仓库：软体夹爪 STEP 是否能在 CAD 打开
- reBotArm_control_py：⭐ **优先看 `example/1_damiao_text.py`**（达妙电机示例，对当前调试直接有用）；fk/ik/traj/gravity_sim 是否仍能跑

### 2. 阅读 example/1_damiao_text.py 单电机 REPL 工具

- 是个交互式命令行工具，相当于"DMTool 的 Python 版"
- 支持 enable/disable/set_zero/state/mode/mit/posvel/vel 命令
- 跑前必须改 3 个配置：
  - `CHANNEL`（WSL2: `/dev/ttyACM0`，Windows: `COMx`）
  - `MOTOR_ID` / `FEEDBACK_ID`（电机 CAN ID）
  - `MODEL` ⚠️ 默认 `"4340P"`，但 reBot 小关节是 **`"4310"`**，必须改
- 文件位置：`software/reBotArm_control_py/example/1_damiao_text.py`

### 3. 修正：安装 motorbridge Python 包到 v0.2.4

**背景**：4-29 升级 `software/MotorBridge` submodule 到 v0.2.4，但**只升级了源码**，Python 环境里还是 4-13 装的 v0.1.7 旧版。今天发现并补装。

**之前给错的命令**：`pip install -e software/MotorBridge`
**正确路径**：`pip install -e software/MotorBridge/bindings/python`（Python SDK 在 bindings/ 子目录里，主目录是 Rust 项目）

**WSL2 安装结果**：
```
Found existing installation: motorbridge 0.1.7
Successfully installed motorbridge-0.2.4
```

**验证通过**：
- `pip show motorbridge` → Version: 0.2.4 ✅
- `from motorbridge import Controller, Mode; print('OK')` → OK ✅
- `dir(motorbridge)` 列出完整 API：Controller / Motor / Mode / MotorState + 全套 RID_* 常量 + 达妙专用工具

**新版的好东西**（旧版没有）：
- 寄存器命名常量：`RID_KP_ASR=25`、`RID_KI_ASR=26`、`RID_KP_APR=27`、`RID_KI_APR=28`、`RID_PMAX/VMAX/TMAX`、`RID_CTRL_MODE`、`RID_ESC_ID`、`RID_MST_ID`、`RID_TIMEOUT`
- 达妙专用工具：`DAMIAO_HIGH_IMPACT_RIDS`（高风险写错会失控的）/ `DAMIAO_PROTECTION_RIDS`（保护类）/ `DAMIAO_RW_REGISTERS`（全部可读写）/ `get_damiao_register_spec()`
- 4 种模式常量：`MODE_MIT` / `MODE_POS_VEL` / `MODE_VEL` / `MODE_FORCE_POS`

**新版的小坑**：
- 不再提供 `motorbridge.__version__`，查版本必须用 `pip show motorbridge`

**Why**：`pip install -e software/MotorBridge` 会失败因为根目录是 Rust 项目（`Cargo.toml`），Python SDK 在 `bindings/python/`。

---

## 2026-04-29

### 1. 为电机说明书 MD 文档添加图片

- 用 PyMuPDF 从 PDF 提取 80 张原始高清图片到 `hardware/reBot_B601_DM/Motor_Datasheets/docs_md/images/`
- 第一次用 pdfplumber 提取图片质量差，重新用 fitz (PyMuPDF) `extract_image()` 拿到原始字节，质量与 PDF 一致
- 把关键图片嵌入到对应 MD 章节：
  - `01_产品介绍.md` - 电机外观、命名规则
  - `02_产品规格.md` - TN 曲线
  - `03_硬件说明.md` - 接口线序、尺寸安装图
  - `04_工作模式.md` - 4 种控制模式框图
  - `06_电机调试流程.md` - 校准波形图、调试界面
  - `07_调试操作.md` - 各模式调试界面截图
  - `08_固件升级.md` - 版本查看、升级界面
  - `09_调试助手使用.md` - 连接界面

### 2. 调试达妙电机 DM-J4310-2EC，发现调试工具版本问题

**问题现象**：
- 使用 `Debugging_Tools_v.1.6.8.8.exe` 调试电机时，串口在校准等操作中频繁出现乱码
- 反馈帧 ID 不一致（一会儿是 6，一会儿是 4）
- 读取参数命令无响应
- 校准时提示"数据传输失败"
- 反馈状态码 ERR=3（输出轴校准异常）

**根本原因**：
- **调试工具版本不兼容**！`Debugging_Tools_v.1.6.8.8.exe` 与电机固件不匹配
- 正确工具应使用：`DMTool v2.1.6.0-FD加速(1).exe`

**工具位置**：
- 错误版本：`hardware/测试工具/Debugging_Tools_v.1.6.8.8.exe`（不要用）
- ✅ 正确版本：`hardware/测试工具/DMTool v2.1.6.0-FD加速(1).exe`

**经验教训**：
- 达妙电机调试必须使用配套版本的 DMTool
- 文档要求 V2.0.0.0 及以上版本，但实际需要 v2.1.6.0-FD 才能稳定通信
- 遇到串口乱码、ID 错乱、读参数无响应等问题，**先排查工具版本**

### 3. 学习达妙电机 4 种控制模式

- 通过 CAN 命令实测：发送使能 + 速度命令，确认 CAN 通信流程
- 解析反馈帧字节含义：D[0] 高 4 位是错误码 ERR，低 4 位是 ID
- 学到 MIT 模式的来源（MIT Cheetah 机器人）和 PVT 模式的含义（Position+Velocity+Torque）
- 详细总结见 `学习笔记.md`

### 4. 检查上游更新

- 主仓库 `Seeed-Projects/reBot-DevArm` ✅ 无新提交
- Submodules 有更新但**暂不同步**：
  - `software/MotorBridge`: 50 个新提交（架构重构 + 版本 0.1.8→0.2.4），改动太大，等用到再升级
  - `software/reBotArm_control_py`: 0 个新提交
  - `遥操作/StarArm_102`: 4 个新提交（模型更新），等遥操作开发时再同步
- 详见 `上游更新记录/2026-04-29_同步详情.md`

### 5. 调整 .gitignore 和文件结构

- `.gitignore` 新增：
  - `hardware/测试工具/`（DMTool 等 exe 文件 33MB，太大不适合上传）
  - `hardware/测试数据/`（个人调试数据，对别人没用）
- 项目总览和操作日志中保留这两个目录的说明（让 AI 知道本地有但不在 git 里）

### 6. 确立"复刻基线维护原则"

**背景**：检查上游时发现 MotorBridge 有 50 个新提交，引发对项目同步策略的根本讨论。

**核心结论**：
- 项目定位是**复刻集成工程**，不是单一软件包维护
- 目标：**持续追上游最新进展**，但 main 分支只接受**验证过的最新**
- 一句话原则：追最新，但不盲目追最新；更新必须记录来源、原因、验证结果和回滚点
- 三层结构：sync 分支（试升级）→ main（已验证的最新）→ baseline tag（阶段性快照）
- 所有 4 个核心依赖都应 fork 到 fanhao375 账号下（Seeed/MotorBridge/reBotArm_control_py/Star-Arm-102）
- 主仓库 submodule 永远只指向自己的 fork
- 每次同步检查都要记录，不同步也要写原因 + 下次触发条件
- Submodule 升级必须走 sync 分支 + 验证流程
- 不擅自 push、不擅自改 .gitmodules、不擅自升级 submodule

**落地动作**（阶段 A，今天完成）：
- 新建 `复刻基线维护原则.md`（主仓库根目录，作为最高规则文档）
- 更新 `项目总览.md` AI 接手提示（明确读文档顺序 + 核心定位）
- 本日志记录决策过程

**核心定位修正记录**：
- 初稿写的是"5 年后 clone 还能跑，不追最新"
- 用户指出表述不准确："不追最新"会误解成保守不动，实际是"追最新但有质量门"
- 修正为"持续追上游最新进展，但 main 分支只接受验证过的最新"
- 这个修正不改变方向，是把复刻基线从"静态快照"概念改成"持续验证的滚动基线"

**待办**（阶段 B，需用户配合）：
- [x] 用户 fork motorbridge/motorbridge → fanhao375/motorbridge
- [x] 用户 fork servodevelop/Star-Arm-102 → fanhao375/Star-Arm-102
- [x] 修改 `.gitmodules` 指向自己的 fork
- [x] 在每个 fork 内配置 upstream remote
- [x] 在当前锁定的 commit 上打本地 baseline tag：`baseline-2026-04-29`（待用户确认后再 push tag）
- [x] 单独 commit submodule URL 变更

### 7. 补充 Git 操作指南

把今天做的复杂 git 操作沉淀到 `Git操作指南.md`，新增"进阶：复刻工程的 Git 操作"章节，含 8 个主题：

1. 检查上游有没有更新（主仓库 + submodule）
2. 把 submodule 切换到自己的 fork（修改 .gitmodules + sync + 内部 remote 配置）
3. 打 baseline tag（阶段性可复现快照）
4. submodule 升级走 sync 分支（不直接在 main 上做）
5. 中文 commit message 用文件而非 HEREDOC（Windows 下 HEREDOC 会出现字符截断乱码）
6. 撤销刚刚的 commit（reset --soft 而非 amend）
7. commit 要分层（每类工作单独 commit，便于 bisect/revert）
8. 保护 upstream 不被误推送（set-url --push DISABLED）

**Why:** 今天实际操作时遇到了几个不在原 Git 操作指南里的复杂场景，把实战经验沉淀下来给后续协作者参考。零基础部分保持不变，进阶内容是补充。

### 8. 同步 MotorBridge / StarArm_102 到上游最新

**背景**：用户明确要求本地文件跟进上游最新进度。此前"暂不同步"的判断改为"同步但记录验证状态"，符合复刻基线维护原则里的"持续追上游最新进展，main 只接受验证过的最新"。

**同步结果**：
- `software/MotorBridge`: `f63896a` → `f7037b0`（跟进 50 个提交，版本到 v0.2.4 附近）
- `遥操作/StarArm_102`: `aaa80d7` → `d777473`（跟进 4 个提交）
- `software/reBotArm_control_py`: 无更新，保持 `a5078ae`

**主要变化**：
- MotorBridge：Studio UI 拆到 `motorbridge/motorbridge-studio`，Python 包版本升级到 0.2.4，达妙寄存器值同步，RobStride 参数兼容性和模式切换稳定性改进，新增 macOS PCBUSB PCAN / standalone gateway 等能力。
- StarArm_102：更新 README / Hardware Overview / Joint Limit，更新 ROS2 Gazebo 模型、URDF、MoveIt/ros2 controller 配置，`link7_left.STL` 和 `link7_right.STL` 文件大小变化明显。

**提交**：
- `7a1bacc` 升级 MotorBridge submodule: `f63896a` → `f7037b0`
- `a132345` 升级 StarArm_102 submodule: `aaa80d7` → `d777473`

**详细记录**：
- `上游更新记录/2026-04-29_submodule升级.md`
- `上游更新记录/2026-04-29_同步详情.md` 已标记为当日早些时候的"暂不同步"旧决策，后续以 submodule 升级记录为准。

**待验证**：
- MotorBridge：Python 安装、`import motorbridge`、示例初始化、与 `reBotArm_control_py` 的兼容性、硬件 CAN/电机扫描/速度模式/位置模式。
- StarArm_102：STL 模型加载、URDF 关节/命名一致性、Joint Limit 变化是否影响遥操作标定。

---

## 2026-04-27

### 整理电机说明书为 Markdown 文档

- 提取 `DM-J4310-2EC V1.2减速电机说明书V1.2定稿.pdf` 全部 45 页内容
- 按章节拆分为 9 个独立 Markdown 文档，保存到 `hardware/reBot_B601_DM/Motor_Datasheets/docs_md/`：
  - `00_目录.md` - 总目录导航
  - `01_产品介绍.md` - 免责声明、注意事项、电机特色
  - `02_产品规格.md` - 特征参数、工作电压、扭矩系数
  - `03_硬件说明.md` - 物品清单、接口线序、指示灯
  - `04_工作模式.md` - MIT/位置速度/速度/力位混控模式
  - `05_CAN通信.md` - 波特率、反馈帧、控制帧、寄存器列表
  - `06_电机调试流程.md` - 连接设备、编码器校准、参数标定
  - `07_调试操作.md` - 各模式详细调试步骤
  - `08_固件升级.md` - 版本查看、串口/CAN 升级
  - `09_调试助手使用.md` - 达妙科技调试助手使用说明
- 清理临时文件：删除 `_pages_18_40/`、`extracted_pages/`、`电机调试指南.md`
- 更新 `hardware/reBot_B601_DM/Motor_Datasheets/README.md`，添加 Markdown 文档导航

**Why:** PDF 不方便 AI 阅读和查询，拆分成 Markdown 后可以快速定位到具体章节，方便调试时查阅。

---

## 2026-04-21

### 同步上游 Seeed-Projects/reBot-DevArm

- `git fetch upstream` + `git merge upstream/main`，merge commit `50a52ee`
- 上游 2 个新 commit（`4420c46..b837833`）：新增腕部相机支架
  - `hardware/reBot_B601_DM/3D_Printed_Parts/D435_Gemini2_Mount.step`（D435i / Gemini 2）
  - `hardware/reBot_B601_DM/3D_Printed_Parts/D405_305_Mount.step`（D405 / Gemini 305）
  - 配套效果图 3 张 + Star Arm 102 主臂图
  - README_zh / README_es 新增"可选硬件"章节（腕部相机 + 主臂选项）
- 新建 `上游更新记录/2026-04-21_同步详情.md` 记录详细内容
- `git push origin main` 推送到 fork

---

## 2026-04-17

### 同步上游仓库 Seeed-Projects/reBot-DevArm

- 修复 git 全局代理为 Clash 端口 `http://127.0.0.1:7890`（原 10808 失效）
- `git fetch upstream` 抓取上游 10 个新提交（b876c69..4420c46）
- `git merge upstream/main` 合并到本地 main，无冲突
  - merge 提交：`36c42ce`
  - 本地未提交修改先 stash，merge 后 pop 恢复
- 上游新增内容：
  - `hardware/reBot_B601_DM/3D_Printed_Parts/01_Joint6_7_Cable Restraint_A.step`（新增，关节 6/7 线缆约束件 A）
  - `hardware/reBot_B601_DM/3D_Printed_Parts/01_Joint6_7_Cable Restraint_B.step`（新增，关节 6/7 线缆约束件 B）
- 上游更新内容：
  - 多语言根 README（购买链接、leader arm 链接、路线图、Python SDK wiki、演示视频、商用条款/免责声明修正）
  - `hardware/reBot_B601_DM/readme*.md` 各语言版本同步更新
- 未影响 `software/reBotArm_control_py` 控制代码目录和 URDF，学习进度不受影响
- 尚未推送到 fork `origin/main`（等确认后再 push）

---

## 2026-04-12

### 1. 同步官方仓库
- `git pull origin main` 拉取最新代码（11个新提交）
- 主要变化：Python SDK 和 Pinocchio 标记为✅完成，指向外部仓库

### 2. 补充硬件资料
- 新建 `hardware/reBot_B601_DM/Motor_Datasheets/`
  - 下载 `DM-J4310-2EC_V1.1_Manual.pdf`（达妙小电机说明书）
  - 下载 `DM-J4340P-2EC_Manual.pdf`（达妙大电机说明书）
  - 编写 `README.md` 电机参数汇总 + CAN 协议整理
- 编写 `hardware/reBot_B601_DM/Hardware_Summary_zh.md` 硬件总结文档

### 3. 拉取软件仓库
- 新建 `software/` 目录
- 克隆 `MotorBridge`（github.com/tianrking/MotorBridge）→ `software/MotorBridge/`
  - 底层通用电机控制栈，Rust 核心 + Python/C++ 绑定
  - 支持达妙、RobStride、MyActuator、HighTorque、Hexfellow 五个品牌
- 克隆 `reBotArm_control_py`（github.com/vectorBH6/reBotArm_control_py）→ `software/reBotArm_control_py/`
  - 上层运动学控制库，基于 Pinocchio
  - 注意：代码在 **develop 分支**，main 分支只有一个空 README
  - 包含 URDF 模型、正逆运动学、轨迹规划、重力补偿、示例程序

### 4. 抓取 wiki 教程
- 用 OpenCLI 抓取 Pinocchio 教程页面 → `software/wiki_docs/`
- 原始 URL：https://wiki.seeedstudio.com/rebot_arm_b601_dm_pinocchio_meshcat/

### 5. 编写说明文档
- `PROJECT_NOTE.md` — 项目总览，文件结构说明
- `software/README_zh.md` — 软件部分详细说明 + 学习路径
- `software/architecture_diagram.md` — 控制架构说明（Mermaid 格式）
- `software/architecture_diagram.png` — 控制架构图（PNG 渲染）
- `software/architecture_diagram.drawio` — 控制架构图（可编辑 Draw.io 格式）

### 6. 环境调整
- `software/reBotArm_control_py/pyproject.toml` 中 `requires-python` 从 `==3.10.*` 改为 `>=3.10`
  - 原因：本机只有 Python 3.12/3.13，放宽版本限制
- 安装依赖：meshcat、numpy、pyyaml、matplotlib
- pinocchio (pin) 待安装

### 7. VS Code 插件
- 安装 `bierner.markdown-mermaid`（Mermaid 预览）
- 安装 `hediet.vscode-drawio`（Draw.io 可视化编辑）
- 以上插件装在 VS Code（F:\vscode\），不是 Cursor（D:\cursor\）

### 8. 文档体系建立
- 新建 `LEARNING_LOG.md` — 学习笔记（踩坑、理解、发现）
- 新建 `LEARNING_GUIDE_01.md` — 复现教程（环境搭建 + 运动学 + 电机控制）
- 确立 5 个文档的分工规则，写入 AI 记忆

---

## 2026-04-13

### 1. WSL2 Ubuntu 22.04 安装
- 目标：Pinocchio 在 Windows pip 编译卡死，改用 WSL2 Linux 环境
- 开启 WSL 功能：`wsl --install --no-distribution`，重启电脑
- 下载 Ubuntu 22.04 镜像：从微软官方下载 appx 包（1.1GB），需设置代理端口 7890
- 安装位置：**F:\WSL\Ubuntu**（C 盘空间不足，通过 --import 直接装到 F 盘）
- 安装步骤：appx → 解压 → 找到 install.tar.gz → `wsl --import` 到 F 盘
- 状态：✅ Ubuntu 已进入，Python 环境待配置

### 2. WSL2 Python 环境配置
- Ubuntu 自带 Python 3.10.12
- 用清华镜像安装全部依赖：`pip3 install pin numpy pyyaml matplotlib meshcat motorbridge -i https://pypi.tuna.tsinghua.edu.cn/simple`
- Pinocchio 3.9.0 安装成功（Linux 下有预编译二进制，秒装）
- 状态：✅ 环境就绪

### 3. 正运动学测试通过
- 运行 `python3 example/5_fk_test.py`
- 归零位置末端：X=0.253m, Y=0, Z=0.172m，URDF 模型验证正确
- 状态：✅ 通过

### 4. 逆运动学测试 — 修复官方 bug 后通过
- `example/6_ik_test.py` 原始代码有 bug，接口参数名与库不匹配：
  - `model=model` → 函数不接受此参数（内部自动加载）
  - `target_position` → 实际参数名为 `target_pos`
  - `target_rotation` → 实际参数名为 `target_rot`
  - 返回值字段 `converged` → 实际为 `success`
  - 返回值字段 `residual_trans/residual_rot` → 实际为 `error`
- 修复后测试：输入归零位置坐标 (0.253, 0, 0.172) → 解出 (0,0,0,0,0,0)，结果正确
- 状态：✅ 修复并通过

### 5. reBotArm_control_py 代码架构梳理
- 通读 develop 分支代码（main 分支是空的）
- 更新 `software/reBotArm_control_py_architecture.drawio` 架构图
  - 原图 dynamics 只画了 4 个功能框，实际有 7 个文件（补全 forward_dynamics / inertia / centroidal / derivatives / energy）
  - trajectory 子模块文件名修正为实际文件：sampler.py / clik_tracker.py / trajectory_planner.py
  - 补充 kinematics 和 dynamics **各有一个** robot_model.py 的说明
  - 硬件接口层细化：motorbridge.Controller + Mode 枚举 + 串口桥 + CAN
  - 增加外部依赖：motorbridge SDK、matplotlib
- 新建 `software/reBotArm_control_py_说明.md`
  - 一句话总结 + 目录结构 + 四个核心子模块详解（每个文件的核心函数）
  - 控制器 ArmEndPos 用法 + 三种控制模式对比（MIT / POS_VEL / VEL）
  - 示例程序索引（0~10）+ robot.yaml 配置说明
  - 完整调用链路（move_to_traj 为例）+ 外部依赖一览

### 6. 运行流程图（末端坐标 → 电机转动）
- 新建 `software/reBotArm_control_py_运行流程.drawio`
  - 回答「这个库怎么把 (x,y,z) 翻译成电机指令」的问题
  - 三条执行路径并列展示：
    - **路径 A（红）**：`move_to_traj()` 轨迹规划 — IK → FK → SE(3)测地线 → CLIK → _send_loop
    - **路径 B（蓝）**：`move_to_ik()` 直达模式 — 只做 IK，一步到位
    - **路径 C（绿）**：重力补偿 — MIT 模式 + g(q) 前馈力矩
  - 三条路径最终汇入 500Hz 公共控制循环 → MotorBridge → CAN → 电机
- 每个流程节点都标注了**源文件路径 + 函数名**，方便对照代码阅读
  - 例如 IK 步骤标注 `controllers/arm_endpos_controller.py → _solve_ik()` + `kinematics/inverse_kinematics.py → solve_ik()`
  - 重力计算标注 `dynamics/inverse_dynamics.py → compute_generalized_gravity()`
  - 底层指令标注 `actuator/arm.py → RobotArm.pos_vel() / mit() / get_state()`

### 7. MotorBridge 代码架构梳理
- 通读 MotorBridge 仓库（Rust workspace 多 crate 结构）
- 新建 `software/MotorBridge_说明.md`
  - 一句话总结 + 项目本质（Rust Cargo workspace）
  - 完整目录结构（motor_core / motor_abi / motor_vendors/{damiao,robstride,...} / bindings/{python,cpp}）
  - **五层调用栈** ASCII 图：用户代码 → Python 绑定 → C ABI → 厂商驱动 → 核心+硬件层 → CAN 总线
  - Python API 7 大块（创建 Controller / 添加电机 / 使能 / 4 种控制模式 / 读状态 / 寄存器 / 清理）
  - 达妙 9 款电机型号表（pmax/vmax/tmax，标注 reBot 用 4310 + 4340P）
  - 4 种控制模式对比表（MIT / POS_VEL / VEL / FORCE_POS）
  - 多线程模型说明（polling_thread 后台接收，缓存 + 直发互不干扰）
  - **与 reBotArm_control_py 的映射关系表**（RobotArm 方法 ↔ MotorBridge API）
  - 完整调用链示例（send_mit 6 层穿透到 CAN 帧）
  - 入口文件索引（按需读什么文件）
- 新建 `software/MotorBridge_architecture.drawio`
  - 5 层水平横条架构图（用户代码 / Python 绑定 / C ABI / 厂商 / 核心+总线 / 硬件）
  - 每层列出所有构成文件，并展开 damiao 子框（motor.rs/protocol.rs/controller.rs/registers.rs）
  - 层间用箭头标注转换方式（ctypes FFI / trait dispatch / CAN encode 等）
- 新建 `software/MotorBridge_运行流程.drawio`
  - 双列布局：**左列发送流（红，自上而下 10 步）** + **右列反馈流（蓝，自下而上 7 步）**
  - 每个步骤标注源文件路径 + 函数名（📂 风格与 reBotArm_control_py 流程图一致）
  - 中间共享状态缓存框（💾）连接两条路径（写：on_feedback；读：get_state）
  - 跨列耦合箭头：电机执行 → 反馈广播
  - 底部 4 条关键理解注释（异步、缓存、多线程安全、跨厂商通用性）

### 8. MeshCat 可视化三件套（无硬件学习）
- **环境修复**：WSL2 访问 Windows 文件时 Git symlink 失效
  - `urdf/reBot-DevArm_description_fixend` 在 Windows 下被存成文本文件（31 字节）
  - 手动在 WSL2 里重建软链接：`ln -s reBot-DevArm_fixend_description reBot-DevArm_description_fixend`
- 跑通 `example/sim/fk_sim.py`（正运动学可视化）
  - 输入关节角 → 浏览器 `http://127.0.0.1:7000/static/` 实时显示 3D 机械臂姿态
  - 测试归零位 `0 0 0 0 0 0` 和复杂姿态 `45 -30 15 -60 90 180`
- **改进 `example/sim/ik_sim.py`（逆运动学可视化）**
  - 原版问题：缺少目标点可视化，每次从零位出发导致不收敛
  - 改进 1：添加 `viz.show_ik_pose()` 调用，显示红球 + 三色坐标轴
  - 改进 2：保存 `q_current`，使用上一次的解作为下一次初值（连续求解策略）
  - 改进 3：增强调试输出，解析失败时显示原始输入
  - 测试结果：三个点全部收敛（`0.25 0.0 0.2` / `0.3 0.0 0.25` / `0.2 0.15 0.3`），迭代 9-12 次，误差 < 0.07mm
- **跑通 `example/sim/traj_sim.py`（SE(3) 测地线轨迹规划 + CLIK 跟踪）⭐**
  - 测试 1：`0.3 0.0 0.25` → IK 成功率 96.1%，误差 0.05mm，51 点 1.0s
  - 测试 2：`0.2 0.15 0.35 0 0.5 0.3`（含姿态）→ **IK 成功率 100%**，误差 0.057mm，121 点 2.4s，6 关节全动
  - 测试 3：`0.15 0.2 0.3` → IK 无解（超出工作空间）
  - 浏览器显示：灰色参考路径 + 绿色实际路径 + 机械臂动画回放
  - **这是 `reBotArm_control_py_运行流程.drawio` 里路径 A（move_to_traj）的无硬件版**
- 关键收获：
  - MeshCat = 浏览器里的"数字孪生"，无需硬件即可验证运动学算法
  - 零位末端位置 `(0.253, 0.000, 0.172)` m
  - 推荐工作半径 < 450mm（70% reach）
  - CLIK 跟踪精度 < 0.1mm，算法实现质量高

### 9. 新手友好文档编写
- 新建 `software/URDF_入门指南.md`
  - 面向机械工程师/硬件工程师的 URDF 快速入门
  - 用机械图纸类比解释 Link（零件）和 Joint（连接方式）
  - reBot-DevArm URDF 结构详解（6 个关节对应的实体零件和电机型号）
  - 关键参数解读（关节轴心位置、转动范围、扭矩限制、质量惯性）
  - 常见操作（修改关节限位、更新零件质量、添加末端工具）
  - 工具推荐（urdf_viz / RViz / check_urdf）
  - 常见问题排查（mesh 找不到、关节限位冲突、质量参数不准）
- 新建 `software/MeshCat_可视化指南.md`
  - 面向机械工程师/硬件工程师的 MeshCat 快速上手教程
  - 什么是 MeshCat（浏览器里的 3D 预览工具）
  - 工作原理（Python 后端 + WebSocket + Three.js 前端）
  - 三个可视化工具详解（fk_sim / ik_sim / traj_sim）
  - 浏览器操作指南（旋转/平移/缩放视角）
  - 常见问题排查（代理拦截、URDF 路径错误、WebGL 未启用、动画卡顿）
  - 高级技巧（录屏、自定义标记、多机器人同时显示）
- 新建 `software/reBot-DevArm_URDF详解.md`
  - 逐行解读 `reBot-DevArm_fixend.urdf` 文件（448 行完整注释）
  - 每个 link 的惯性参数含义（质量、质心、转动惯量）
  - 每个 joint 的关键参数（origin 位置、rpy 旋转、axis 转轴、limit 限位）
  - 为什么 joint2 的 `rpy="-1.5708 0 0"`（坐标系旋转 90°）
  - 为什么 joint2 的 `upper="0"`（机械限位，不能往上抬超过水平）
  - 为什么 link2 质量最重（1.327kg，包含大臂和肘关节电机）
  - 末端 end_joint 为什么是 `type="fixed"`（法兰固定连接）
  - 完整的机械结构对应关系（URDF 名称 ↔ 实体零件 ↔ 电机型号）
- **目标**：让不懂 ROS/Pinocchio 的硬件工程师也能快速上手可视化工具，看懂 URDF 每一行的物理含义

### 10. 文档归类整理
- 将新手文档从 `software/` 根目录移入 `software/docs/` 分类文件夹：
  - `docs/00_新手入门/` — URDF 入门指南、MeshCat 可视化指南
  - `docs/01_项目专用/` — reBot-DevArm URDF 详解
  - `docs/02_reBotArm_control_py/` — 运动学控制库架构说明、架构图、运行流程图
  - `docs/03_MotorBridge/` — 底层电机库架构说明、架构图、运行流程图
- 每个文件夹编写 `README.md` 索引
- 编写 `software/docs/README.md` 文档中心导航（3 条学习路径 + 速查表）
- 更新 `software/README_zh.md` 目录结构和学习路径（新增"第零阶段：看文档"）

---

## 2026-04-14

### 1. 抓取 Wiki 文档（OpenCLI）
- 修复 OpenCLI 使用问题：`generate/explore` 命令在当前环境报错，改用 `web read` 命令成功
- 正确命令：`opencli web read --url <URL> --output <DIR> --download-images true`
- 抓取以下页面到 `software/wiki_docs/`：

| 页面 | 大小 | 关系 |
|---|---|---|
| 达妙系列电机 | 41.5 KB | 直接相关 — 项目使用的电机 |
| RobStride 电机控制完整指南 | 20.2 KB | 直接相关 — RS 版本会用 |
| DM Gripper 夹爪组装指南 | 6.2 KB | 直接相关 — 末端执行器 |
| SoArm in LeRobot | 85.1 KB | 参考 — 路线图 LeRobot 适配 |
| StarAI Arm in ROS2 MoveIt | 7.7 KB | 参考 — 路线图 MoveIt2 适配 |
| ROS2 Humble 安装教程 | 3.8 KB | 参考 — ROS2 基础环境 |
| Robotics 总页面 | 5.4 KB | 索引 — 全部机器人资源导航 |

### 2. 电机 Wiki 双份存放
- 硬件相关的 wiki（达妙电机、RobStride、DM Gripper）复制到 `hardware/reBot_B601_DM/Motor_Wiki/`
- `software/wiki_docs/` 保留完整副本
- 两处各编写 `README.md` 索引文档

### 3. Wiki 文档格式修复
- OpenCLI 抓取的 HTML 表格全部变成了一行一个值的纯文本，代码块被压成单行
- 逐个修复全部 5 个有问题的文档：

| 文档 | 修复内容 |
|---|---|
| 达妙系列电机 | 规格参数表拆成 3 个表格（基础规格/电气参数/控制参数），Python 代码（damiao_motor.py + damiao_test.py）恢复缩进 |
| RobStride 电机控制完整指南 | 5 个表格重建（电机型号/语言对比/CAN帧格式/性能基准/错误代码），30+ 处代码块恢复换行 |
| DM Gripper 夹爪 | 5 个 BOM 分类表格重建，警告块格式化 |
| StarAI Arm MoveIt | 规格表重建（3 款机械臂对比），C++ 代码恢复，shell 命令拆行 |
| SoArm LeRobot | 7 个表格重建，50+ 处代码块恢复，JSON 配置恢复缩进，警告块修复 |

- 同步修复后的电机文档到 `hardware/reBot_B601_DM/Motor_Wiki/` 副本

### 4. MeshCat 仿真代码详解文档
- 新建 `software/docs/01_项目专用/reBot-DevArm_MeshCat仿真代码详解.md`
- 对 4 个仿真文件逐函数解读：
  - `visualizer.py` — Visualizer 类初始化流程、6 个核心方法（update/show_ik_pose/draw_path/play_trajectory 等）
  - `fk_sim.py` — 正运动学可视化流程（输入关节角 → 计算末端位姿 → 浏览器显示）
  - `ik_sim.py` — 逆运动学可视化流程（输入目标位姿 → 解算关节角 → 连续初值策略）
  - `traj_sim.py` — 轨迹规划仿真流程（SE(3)测地线 → CLIK跟踪 → MeshCat动画回放）
- 包含调用关系图、关键参数说明、仿真 ↔ 真机代码映射表、核心概念速查
- 更新 `software/docs/01_项目专用/README.md` 索引和 `software/docs/README.md` 速查表及学习路径

### 5. Fork 到 GitHub + Git 操作指南
- 在 GitHub 上 Fork 官方仓库到 `fanhao375/reBot-DevArm`
- 配置本地 git remote：
  - `origin` → 个人 Fork（可推送）
  - `upstream` → 官方仓库（只读，用于同步）
- 配置 git 用户信息（user.name / user.email）
- 提交所有补充内容（160 个文件，12999 行新增）
- 推送到 GitHub（处理 rebase 冲突，同步官方 PR #13 的 Pinocchio 链接更新）
- 新建 `GIT_GUIDE.md` — 零基础 Git 操作指南：
  - 为什么要 Fork（对比直接下载/Clone 的优缺点）
  - 如何在 GitHub 上 Fork 仓库（图文教程）
  - 如何关联本地仓库到 Fork（origin/upstream 配置）
  - 如何提交和推送修改（add/commit/push 完整流程）
  - 如何同步官方仓库更新（pull upstream + push origin）
  - 常见问题排查（换行符/嵌套仓库/认证/撤销提交）
  - 开源协议注意事项（CC BY-NC-SA 4.0 解读）
  - 推荐工作流程（日常开发/定期同步/分支开发）

---

## 2026-04-16

### 1. 安装可视化 Skills（markdown-viewer/skills）
- 克隆 `https://github.com/markdown-viewer/skills` 到 `/tmp/markdown-viewer-skills`
- 软链接 4 个有用的 skills 到全局目录 `~/.claude/skills/`：
  - `uml` — UML 类图、序列图、活动图（PlantUML）
  - `architecture` — 分层架构图（HTML/CSS 嵌入）
  - `infographic` — 流程图、时间线、对比图（YAML 语法）
  - `mindmap` — 思维导图（PlantUML）
- 目的：以后读代码时可以快速生成可视化图表

### 2. 重力补偿代码解析文档
- 新建 `software/docs/02_reBotArm_control_py/重力补偿详解/` 目录
- 生成 4 个文档：
  - `README.md` — 完整教程（7789 字节）
    - 什么是重力补偿（问题 + 解决方案）
    - 物理原理（动力学方程 τ = M·q̈ + C·q̇ + g(q)）
    - 数学推导（RNEA 算法 + MIT 控制律）
    - 代码架构（4 层架构）
    - 代码详解（核心代码逐行解释）
    - 实战示例（9 号和 10 号例程）
    - 常见问题（FAQ）
  - `architecture_代码架构.md` — 4 层架构图（HTML/CSS）
    - 业务层（蓝色）：9/10 号例程
    - 封装层（紫色）：dynamics API
    - 计算层（绿色）：inverse_dynamics + inertia
    - 底层（红色）：Pinocchio
  - `sequence_函数调用序列.md` — UML 序列图
    - 用户代码 → 控制循环 → API → 计算层 → Pinocchio
    - 500Hz 循环的完整调用链
  - `control_loop_控制循环流程.md` — Infographic 流程图
    - 5 个步骤：读取关节位置 → 计算重力补偿 → MIT 控制 → 打印力矩 → 循环

### 3. 文档结构统一规范
- 更新 `software/docs/README.md` 速查表，加入重力补偿详解
- 更新 `software/docs/02_reBotArm_control_py/README.md`：
  - 文档列表加入重力补偿详解/
  - 学习路径分为路径 1：运动学入门和路径 2：动力学进阶
- 文件命名规范：统一使用英文_中文格式（如 `sequence_函数调用序列.md`）
- 确保所有代码解析文档都在 `software/docs/` 下，按模块分类

### 4. 同步 upstream 更新
- 配置 git 代理（端口 10808）
- `git fetch upstream` 发现 2 个新提交：
  - `b876c69` Merge pull request #15 from tianrking/patch-1
  - `c3cee75` Create DISCLAIMER.md（免责声明文档）
- DISCLAIMER.md 内容：
  - 产品定位：DIY 套件，需自行组装调试
  - 安全风险：高速高扭矩，可能夹伤、撞击、砸伤
  - 责任划分：厂家只对出厂材料缺陷负责，用户自行组装错误/超载/改装等导致的事故不负责
  - 禁止场景：医疗、生命支持、载人、水下、工业高危等
  - 免保条款：拆机、改装、进水、过保、无发票等不保修

### 5. 修复图表渲染问题（PlantUML/Infographic → Mermaid）
- 问题：VS Code 中除 `architecture_代码架构.md`（HTML/CSS）外，PlantUML 序列图和 Infographic 流程图都无法直接渲染（需要额外插件/浏览器扩展）
- 解决：利用已安装的 `bierner.markdown-mermaid` 插件，把两个不渲染的图改写为 mermaid 格式
- 改动文件：
  - `sequence_函数调用序列.md` — PlantUML `@startuml` → `mermaid sequenceDiagram`
    - 保留 actor / participant / activate / Note 语义
    - 末尾追加一个简化的 `flowchart LR` 调用层次图
  - `control_loop_控制循环流程.md` — Infographic YAML → `mermaid flowchart TD`
    - 5 个步骤节点 + 循环判断
    - 用 `classDef` 着色：初始化（蓝）/ 循环体（黄）/ 计算（红）/ 控制（绿）/ 结束（紫）
- 选型理由：mermaid 在 VS Code、GitHub、Typora 都原生支持，跨平台一致；HTML/CSS 架构图也保留（universal 渲染）

### 6. 建立 Codex 本地项目记忆
- 新建本地目录 `.codex/`，用于存放 Codex 专用项目记忆快照
- 新建 `.codex/PROJECT_MEMORY_项目记忆.md`
  - 来源：`小红书进度/AI_HANDOFF_AI接手指南.md`
  - 同步内容：
    - 项目定位与当前阶段
    - 文档体系分工与自动更新规则
    - 环境约束（VS Code 路径、Pinocchio/WSL2、Git 代理 10808）
    - 图表规范（首选 Mermaid，其次 HTML/CSS）
    - 小红书子项目分离规则与工具链约定
    - OpenCLI 用法、命名规范、常见翻车点
- 更新 `.gitignore`：忽略 `.codex/`，确保该记忆文件只做本地使用、不上传 GitHub
- 更新 `PROJECT_NOTE.md`：登记 `.codex/` 本地工具目录和本次新增记忆文件

### 7. 补齐重力补偿仿真版（example/sim/gravity_sim.py）
- 背景：`example/sim/` 下原有 fk_sim / ik_sim / traj_sim 三件套（对应作者真机例程 5/6/8 号），唯独 9/10 号重力补偿没有仿真版
- 新建 `software/reBotArm_control_py/example/sim/gravity_sim.py`（约 170 行）
  - 对应真机例程：`example/9_gravity_compensation.py`
  - 模式参考：`example/sim/fk_sim.py`（交互输入关节角）
  - 复用 `example/sim/visualizer.py` 的 `Visualizer` 类，通过其 `meshcat` 属性扩展自定义节点
- 功能：
  - 交互输入 6 个关节角（度）→ MeshCat 实时显示姿态
  - 在每个 link 质心位置画**红色球**（半径 ∝ √质量）
  - 从每个质心向下画**绿色重力线段**（长度 ∝ m·g）
  - 终端打印 6 个关节的 τ_g（带条形图，附 max 和 Σ|τ_g|）
- 关键 Pinocchio API：
  - `model.inertias[i].mass` / `.lever` — link i 的质量和质心（局部坐标）
  - `data.oMi[i].act(lever)` — 质心转世界坐标
  - `compute_generalized_gravity(model, q, data)` 内部已更新 `data.oMi`，无需重复 forwardKinematics
- 后续：跑通后整理小红书素材（推荐姿态对比图：归零 vs 大臂水平 vs 折叠）

### 8. 修复 gravity_sim.py 上游 API 不兼容
- 症状：`get_gravity(model)` 报 `AttributeError: 'numpy.ndarray' object has no attribute 'x'`
- 根因：上游 `dynamics/robot_model.py:133` 用 `g.linear.x/.y/.z` 取分量，这是 Pinocchio 2.x 的 API；新版 3.9.0 已把 `pin.Motion.linear` 改成直接返回 `numpy.ndarray`
- 处理：**不动上游**（避免和官方分叉），在 `gravity_sim.py` 里用 `np.asarray(model.gravity.linear)` 直接读
- 附记：这类 `Motion.linear.x` / `Placement.translation.x` 的老 API 在上游可能还有，遇到再绕

--- 

---

## 2026-04-22

### 1. 电机说明书版本整理
- 新增最新版说明书 PDF：
  - `DM-J4310-2EC V1.2减速电机说明书V1.2定稿.pdf`（2025.11，对应关节 2-5 小关节）
  - `DM-J4340-2ECV1.1减速电机说明书 V1.1 定稿.pdf`（2025.11，45 页完整版，对应关节 1 和肩部大关节）
- 旧版 PDF 归档到 `Motor_Datasheets/旧版/`（V1.0/V1.1 保留备查）
- 更新 `Motor_Datasheets/README.md`：文件名、章节标题同步为最新版本号
- 用 pypdf 验证新版 PDF 比旧版内容更完整（J4340：14页→45页，版本 V1.0→V1.1）

### 2. 新建遥操作系统目录
- 在项目根目录新建 `遥操作/` 文件夹
- 以 git submodule 方式引入 [servodevelop/Star-Arm-102](https://github.com/servodevelop/Star-Arm-102) → `遥操作/StarArm_102/`
- 编写 `遥操作/README.md`：遥操作概念说明、Star Arm 102-LD 与 reBot Arm B601 的主从关系、LeRobot 数据采集工作流、submodule 初始化命令
- 更新 `PROJECT_NOTE.md` 项目结构树，添加 `遥操作/` 条目

---

## 2026-04-23

### 1. 五个自建文档重命名为中文
- `CHANGELOG.md` → `操作日志.md`
- `PROJECT_NOTE.md` → `项目总览.md`
- `LEARNING_LOG.md` → `学习笔记.md`
- `LEARNING_GUIDE_01.md` → `复现教程_01.md`
- `GIT_GUIDE.md` → `Git操作指南.md`
- 用 `git mv` 保留历史，同步更新 `software/docs/README.md`、`software/docs/00_新手入门/README.md`、`上游更新记录/README.md`、`Git操作指南.md` 里的所有引用

### 2. 新增重力补偿锁止仿真（教学解剖版）
- 新建 `software/reBotArm_control_py/example/sim/gravity_lock_sim.py`
- 对应真机例程 `10_gravity_compensation_lock.py`（末端速度锁止版重力补偿）
- 不做动力学积分，而是"静态解剖式"把 10 号的控制律分 5 步打印：
  1. 雅可比 J(q) 形状
  2. 末端线速度 v_ee = J[:3] · q̇ 和角速度 w_ee = J[3:] · q̇
  3. 阈值判断（V_TH=0.04 m/s, W_TH=0.08 rad/s）
  4. LOCKED 保持 q_target / UPDATE 跟随当前 q
  5. 最终 τ = τ_g + kp·(q_target - q) + kd·(0 - q̇)，每项带条形图
- MeshCat 可视化：末端线速度蓝色箭头 + 角速度橙色箭头 + 锁止状态球（绿=LOCKED，红=UPDATE）
- 4 个预设场景（s0 归零静止 / s1 微扰动 / s2 人在推 / s3 末端快转）

### 3. 同步上游 2026-04-23
- 上游 commit 范围：`b837833..33f57b2`（6 个 commit），本地 merge commit：`1c1bfe1`
- 核心更新：官方新增「深度相机视觉抓取 Demo」状态行（YOLO + 深度相机）
- D405 相机支架 STEP 小修订；4 个翻译版 README 的 Pinocchio 链接换成 GitHub 仓库地址
- 新建 `上游更新记录/2026-04-23_同步详情.md` 记录详细内容
- 更新 `项目总览.md` 官方更新进度表：组装视频/腕部相机支架/视觉抓取 Demo 标 ✅

### 4. 复现教程补充 WSL2 USB 直通章节
- 在 `复现教程_01.md` 第五步前新增 5.0 小节「WSL2 访问 USB 设备（一次性配置）」
  - 5.0.1 用 `winget install dorssel.usbipd-win` 安装微软官方 USB passthrough 工具
  - 5.0.2 插 USB 后的 `usbipd bind/attach` 两步
  - 5.0.3 拔 USB 前的 `detach`（可选但推荐）
- 同步更新 5.1 硬件连接，补充两条可选路径：
  - 路径 A: 达妙 USB2CAN + MotorBridge（Python SDK，跑真机例程）
  - 路径 B: 创芯 CANalyst-II + ECAN Tools（Windows GUI 验货）
- 实际验证：本机 usbipd-win 已装（v5.3.0），等达妙 USB2CAN 到货后走完整流程

### 5. 事后修正（2026-04-23 晚）
**起因**：用户指出上述第 2、3 条的文档结论写得比证据更满，存在 5 处实质错误。

**修正内容**：
1. **gravity_*_sim.py 未在主仓库**
   - 问题：`操作日志.md` 和 `项目总览.md` 把这两个脚本写成"已新增"，但它们只在 `software/reBotArm_control_py` 未提交工作区里（`??` 状态），主仓库 gitlink 仍指向 962cc8d，别人 clone 拿不到
   - 修正：移动到主仓库 `software/sim_extras/`，作为正式跟踪文件；新建 `software/sim_extras/README.md` 说明这是自建学习脚本目录；修改两个脚本的 `sys.path` 和用法注释

2. **视觉抓取 Demo 链接 404**
   - 问题：`项目总览.md`、`上游更新记录/2026-04-23_同步详情.md` 把"深度相机视觉抓取 Demo"写成已完成并指向官方 wiki，但中英文链接都返回 404
   - 修正：`项目总览.md` 把该行状态改回 🚧，注明"README 加了链接但 wiki 页面 404，疑似抢发"；`上游更新记录/2026-04-23_同步详情.md` 重写，删除所有推断（"Eye-in-Hand 路径彻底跑通""技术栈 = YOLO + 深度图反投影""vectorBH6 是事实上的上游""不需要 ROS2"），只保留事实（"官方在 README 加了这行 + 链接 404"）

3. **中英文 README LeRobot 状态矛盾**
   - 问题：英文 README.md L96 标 ✅ Completed，中文 README_zh.md L94 标 🚧 进行中，`项目总览.md` 按中文汇总但没说明
   - 修正：`项目总览.md` 标题改为"按中文 README_zh.md 汇总"，新增警告框说明中英文冲突、以中文版为准

4. **WSL USB 教程表述不够严谨**
   - 问题：`复现教程_01.md` L285 说"换 USB 口也不用重新绑"（官方文档只说 per-device 持久化，没承诺跨 BUSID）；L291 用 `/dev/ttyACM*/ttyUSB*` 作为通用验证方法（只适合串口类设备，不适合相机）
   - 修正：L285 改为"per-device 持久化，但换 USB 口 BUSID 会变，需重新 bind"；验证方法改用 `lsusb`（通用），并注明串口类设备可额外检查 `/dev/tty*`、相机类设备不会出现在 `/dev/tty*` 里

5. **记忆系统新增纪律**
   - 新增 UTF-8 验证规则：Edit 工具改中文文件后必须立刻 `grep "�"` 验证，不等用户发现（本次修正过程中又引入 2 处乱码，已修复）

**反思**：这几处都犯了同一类错——把"官方 README 新增一行"当成"官方已交付该功能"，没点开链接验证，也没对照其它语言。下次见到"✅ + 外链"至少 curl 确认一下。

### 6. 二次修正（2026-04-23 晚）
**起因**：用户指出上述修正中仍有 4 处文档口径问题。

**修正内容**：
1. **视觉抓取 Demo wiki 已上线**：重新验证链接返回 200，更新 `项目总览.md` 和 `上游更新记录/2026-04-23_同步详情.md`，改回 ✅ 完成
2. **08 号算法编号错误**：`学习笔记.md` 里把 08 号标成"固定目标重力补偿"，但实际 08 号是 `8_arm_traj_control.py`（轨迹控制），已删除错误对比行并加注释
3. **积分项表述修正**：`学习笔记.md` 里"误差 1rad 每秒累积约 1.0 N·m"有误，实际是每个控制周期（2ms）累积，已改为"每个控制周期累积"
4. **操作日志表述修正**：上条"新建 `feedback_utf8_verification.md`"改为"新增 UTF-8 验证规则"（该文件未实际创建）

**反思**：第一次修正时过于匆忙，没有重新验证网络链接状态，也没有仔细核对 example 文件编号。修正文档时也要保持严谨。

### 7. 用 OpenCLI 补抓新上线 wiki（2026-04-23 夜）
**起因**：官方中文 wiki 已上线，需要把新页面离线归档进 `software/wiki_docs/`，同时把正确的 `opencli` 用法记住。

**执行结果**：
1. **确认 opencli 正确用法**
   - 参考项目本地记忆和 OpenCLI 官方仓库说明，`web read` 是正确命令；`Browser Bridge not connected` 是它定义的常见报错
   - 在当前 Windows + Codex 环境里，直接 PowerShell 调 `opencli` 不稳定，改为用 Git Bash 进入 `/c/Users/12440/AppData/Roaming/npm` 执行 `./opencli web read ...`

2. **新增两份离线 wiki 快照**
   - `software/wiki_docs/reBot_Arm_B601-DM_Visual_Grasping_Demo/`
   - `software/wiki_docs/reBot_Arm_B601-DM_in_Lerobot/`
   - 两份文档都保留了本地 `images/` 资源，断网可读

3. **整理归档结构和索引**
   - 拍平 OpenCLI 自动生成的双层目录，保持 `wiki_docs/` 下每篇文档一层目录的现有约定
   - 更新 `software/wiki_docs/README.md`，补充两份新文档并把“最后更新”改为 `2026.04.23`

**反思**：以后在这台机器上用 OpenCLI，优先沿用已验证的 Git Bash 路径和命令模板，不再临时猜 PowerShell 调法。

### 8. 正规化 software 外部仓库为正式 submodule（2026-04-23 夜）
**起因**：`software/MotorBridge` 和 `software/reBotArm_control_py` 之前虽然在索引里是 gitlink，但 `.gitmodules` 没有映射，属于“半挂状态”；clone / pull / 状态判断都容易让人误解。

**处理内容**：
1. 在根目录 `.gitmodules` 中补充：
   - `software/MotorBridge` → `https://github.com/tianrking/MotorBridge.git`（`main`）
   - `software/reBotArm_control_py` → `https://github.com/vectorBH6/reBotArm_control_py.git`（`develop`）
2. 执行 `git submodule absorbgitdirs`，把两个目录从“各自带 `.git/` 的嵌套仓库”收口为主仓库统一管理的标准 submodule 结构
3. 更新 `项目总览.md`、`software/README_zh.md`、`Git操作指南.md`，统一说明：
   - 这是外部仓库，不是官方主仓库原生代码
   - 但当前项目已经以正式 submodule 方式引用它们
   - clone / pull 后需要 `git submodule update --init --recursive`

**边界说明**：
- `software/reBotArm_control_py` 本机还有一个本地提交 `822d342`（清理 `.pyc` + 补 `.gitignore` + 保留有效源码修正）
- 因为还没有你自己的公开 fork 来承接这个提交，所以本次**不更新父仓库 gitlink 到该提交**，只先把 submodule 结构正规化，保证远端可复现

**反思**：以后引入外部仓库，要么一开始就用正式 `git submodule add`，要么彻底 vendoring；不要再长期维持“索引是 gitlink、但 `.gitmodules` 没登记”的中间态。

### 9. 为 reBotArm_control_py 建立个人 fork 并闭环 submodule 更新（2026-04-23 夜）
**起因**：`software/reBotArm_control_py` 已有本地修复提交，若不为子仓库建立可公开访问的远端，主仓库无法安全引用该提交。

**处理内容**：
1. 通过 GitHub API 创建 `fanhao375/reBotArm_control_py`，作为 `vectorBH6/reBotArm_control_py` 的个人 fork
2. 将子仓库 remote 规范为：
   - `origin` → `https://github.com/fanhao375/reBotArm_control_py.git`
   - `upstream` → `https://github.com/vectorBH6/reBotArm_control_py.git`
3. 发现个人 fork 的 `develop` 已领先于本地旧基线 `962cc8d`，因此将本地清理提交重放到 fork 的最新 `develop` 上：
   - 原本地提交：`822d342`
   - 重放后提交：`a5078ae`
4. 将 `a5078ae` 推送到个人 fork 的 `develop`
5. 更新主仓库 `.gitmodules`，让 `software/reBotArm_control_py` 正式指向个人 fork；随后父仓库可安全更新 gitlink 到 `a5078ae`

**结果**：
- `software/reBotArm_control_py` 的 `.pyc` 清理和本地修复现在已是远端可下载状态
- 主仓库不再依赖“只有本机才有”的子仓库提交
- 以后修改该子仓库的标准流程是：先改 fork，再回主仓库更新 submodule 指针

### 10. 在 项目总览.md 顶部补 AI 接手提示（2026-04-23 夜）
**起因**：希望后续接手的 AI 不用翻长日志，也能一眼看懂 submodule 结构和更新规则。

**补充内容**：
1. 在 `项目总览.md` 顶部新增 `AI 接手提示`
2. 明确三个子模块的：
   - 主要来源仓库
   - 当前 submodule URL
   - 是否只读跟踪 / 是否通过个人 fork 承接修复
3. 明确关键规则：
   - clone 要带 `--recurse-submodules`
   - pull 后要跑 `git submodule update --init --recursive`
   - 主仓库锁定的是子模块提交号，不是分支名
   - `reBotArm_control_py` 如需同步源码上游，先看 `upstream/develop`

**结果**：以后别的 AI 只要先读 `项目总览.md`，就能知道这块不是普通目录，避免再把 submodule 当成普通文件夹乱改。

---

## 2026-04-26

### 同步上游：reBot v1.0 → v1.1 重大版本更新

- 上游 commit 范围：`33f57b2..c337d44`（2 个 commit），本地 merge commit：`c3e730e`
- 官方 changelog（4 点）：
  1. 末端 3 个关节加线束卡口（防松防脱落）
  2. 关节 1 电机型号修正：4310 → 4340P
  3. 底部新增 CNC 件 `02_Base_Reinforcement_Part.step` 加强强度
  4. 新增线束卡扣
- 整机文件改名：`reBot_B601_DM_v1.0_20260331.step` → `reBot_B601_DM_v1.1_20260425.step`
- 新增零件：`02_Rack` / `03_Link1~5` / `Gemini2_mount` / `UVC32_mount` / 3 个 Cable Restraint
- BOM 关键变化：齿轮内孔 5 → 内孔 8、螺丝体系细分（HM/KM 多型号）、铜柱 M4*50 取消、定位销 M4*8 → M4*7
- 5 语言版 README 全更新；新增 `media/v1.1.png` 和 `v1.1_2.png` 整机预览图
- 详细见 `上游更新记录/2026-04-26_同步详情.md`

**对学习项目的影响**：
- 算法层（URDF / 运动学 / 控制代码）不受影响
- 硬件复刻路径需重新规划：齿轮规格变了必须按 v1.1 买、3D 打印件需补打 5 个 Cable Restraint、CNC 件需补加工底座加强件
- 已下单的 3×4340P + 4×4310 电机配置不变（v1.1 修正后 j1 也是 4340P）

---

> ⚠️ **2026-05-05 ~ 2026-05-31 的操作记录补登说明**：这段时间的操作（多次上游同步、Python wheel 升级、装机阶段、LeRobot follower 验证等）当时记在了 `项目总览.md` 的「更新记录」表格里，本操作日志一度断更。自 2026-06-01 起回归原始规则，操作记录恢复登记于本文件。历史明细见 `项目总览.md` 更新记录表 + `上游更新记录/` 各同步详情。

## 2026-06-01

### 1. 从 fork 同步本地（拉另一台电脑的进度）
- `git pull` 拉下另一台电脑 push 到 `origin/main` 的 2 个 commit（`2d9c99e` / `30f0bb1`）：LeRobot follower 验证小白手册 + 重力补偿小白手册 + `tools/lerobot_b601_keyboard_jog.py`，快进同步无冲突。
- 清理 submodule `reBotArm_control_py` 内一个 `.pyc` 噪声（`git checkout` 还原）。

### 2. 提交《AI机器人路径选择扫盲》PDF 并 push fork
- `git add` 根目录 `AI机器人路径选择扫盲.pdf`（882K，配套同名 md），commit `111fd9b`。
- `git push origin main`：首次网络中断（curl 55 Connection reset），`git config http.postBuffer 524288000` 后重试成功。

### 3. 上游同步：DM 电源组装资料 + 摄像头支架 STEP 修正
- 上游 `af0bb58..6f7b33f`（5 commit，全在 `hardware/reBot_B601_DM/`）：摄像头支架 4 STEP 重导出 + 删冗余 UVC32；社区 PR #33（LAN-GER）DM 电源组装资料（电源外壳 STEP×3 + 外购件图×7 + 渲染图×3 + readme 电源章节）。
- ⚠️ **本地化处理**：组装实拍图 `Assembly_Steps/powerstep_images/`（20 张约 94MB）只留本地、不上传 GitHub（加 `.gitignore` + readme 注明在线版见上游）；剔除上游误提交的 `.obsidian/`。
- **技术关键**：用 squash 单亲提交而非 merge，避免上游 commit 成祖先把 94MB 大图带进可推送历史（实证 `git rev-list --objects main` 0 个 powerstep 对象，push 体积 ≈7.78MB）。commit `b1f606b`，文档 commit `8517f45`，打 `baseline-2026-05-31` tag，已 push。
- ⭐ 同步前 spawn subagent 复核影响（风险低）。详见 `上游更新记录/2026-05-31_同步详情.md`。

### 4. 记录引导臂选型落定（遥操作主线决策）
- 用户决定 leader 做 **reBot Arm 102**（舵机到货 + 自己 3D 打印结构件，进入装配）。
- 更新 `遥操作与LeRobot待办.md`：§1/§2/§4 标记已决策，新增 §3.7（官方装配教程未发布）、§3.8（跨系统遥操作 102 leader→B601-DM follower 适配器配对待确认）。commit `70dd56a`。
- 同步更新 memory `project_teleop_leader_choice_risk.md` + `MEMORY.md`。

### 5. 记录摄像头选型结论
- 调研结论：LeRobot AI 主线买**普通 RGB USB 摄像头 ×2**（腕部小模组 + 俯视罗技）即可，**深度相机非必需**（只有官方 YOLO 抓取 demo 才用深度）。
- 更新 `遥操作与LeRobot待办.md`：新增 §3.9（完整论证 + 购物清单），阶段4/支线1 定调。commit `6bccece`。
- 详细原理同步登记到 `学习笔记.md`（见 2026-06-01 条）。

### 6. 文档体系合规补登
- 按项目规则回归：操作记录补登本文件（操作日志），原理理解补登 `学习笔记.md`。

## 2026-06-07

### 1. 云端/本地双向同步对齐
- 检查发现分叉：本地领先 3 个文档 commit（102 选型 / 摄像头选型 / 合规补登），云端领先 1 个 commit `44a123c`（另一台电脑推的《LeRobot_Arm102LD_B601DM遥操作小白执行手册.md》，698 行——正是 §3.8 跨系统遥操作主题）。
- 两边文件零重叠，`git merge origin/main` 干净合并（merge commit `3daacde`），`git push origin main` 推 4 个 commit，云端本地完全对齐。
- 🟡 待办：读新手册，把 `遥操作与LeRobot待办.md` §3.8 的"适配器配对待确认"更新成实际结论。

### 2. 摄像头最终采购决定（推翻"只买 USB"，两条路都玩）
- 用户决定深度 + USB 都买：**Orbbec Gemini 2 已下单（¥1750 实付，天猫奥比中光官方旗舰店，3D 双目结构光）** + 普通 USB 摄像头（俯视，型号待补）。
- Gemini 2 = 官方 YOLO 抓取 demo 同款 + 仓内现成腕部支架 `D435_Gemini2_Mount.step`；计划装腕部（eye-in-hand），其 RGB 流兼当 LeRobot 腕部相机；USB 当俯视。
- 更新 `遥操作与LeRobot待办.md`：§3.9 加"最终采购决定"、阶段4 定调改为实际采购、支线1 表格标注已下单/不买项。

### 3. 上游同步：三仓全部更新到最新（用户拍板"全部更新"）
- ⭐ spawn subagent 复核三仓影响后执行。走 `sync/upstream-2026-06-07` 分支，验证通过 ff 合入 main，打 `baseline-2026-06-07` tag。
- **主仓** `6f7b33f..5606170`（11 commit，squash 单亲法）：README 社区贡献表 + 4 张社区图 + DM 电源上盖/滑盖 STEP XT60E 母座内移修正（打印用此版）。⚠️ 永久约束确认：主仓历史含 94MB blob，以后一律 squash、不可普通 merge upstream。
- **MotorBridge v0.3.9 → v0.4.5**（27 commit）：达妙模式写入重试增强 + `request_fresh_state`；dm-device 可选传输后端复核为**非强制依赖**（wheel 不打包、现有路径零影响）；API 100% 兼容。fork 已 fast-forward push。
- **reBotArmController_ROS2 → c6a4e68**（5 commit）：MoveIt2 Humble 修复 + `fresh()` 用法修正。fork 已 push。
- **Python wheel 升级**：Windows `E:\Python312` 0.3.9→0.4.5 ✅（import + Controller/Mode/add_damiao_motor/from_dm_device 验证过）；WSL 系统 python3 0.3.9→0.4.5 ✅；**LeRobot 环境（miniforge3 conda env `lerobot`）查实在另一台电脑上（本机 WSL 无 conda 无校准缓存），待在那台 pull 后 `conda activate lerobot && pip install -U motorbridge==0.4.5`**。
- ⚠️ 硬件未验证：下次真机上电跑重力补偿确认 0.4.5 正常；异常回滚 `pip install motorbridge==0.3.9` + `baseline-2026-05-31` tag。
- 详见 `上游更新记录/2026-06-07_同步详情.md`。

---

## 2026-06-11

### 上游同步：三仓全部更新到最新（用户拍板"都同步"）
- ⭐ 同步前 spawn 3 个独立 subagent 分仓复核影响（主仓 / MotorBridge / control_py），结论均回写详情文件；subagent 纠正我一处背景误判（control_py develop 与 main 是真分叉，非单纯领先）。
- 走 `sync/upstream-2026-06-11` 分支，3 个源码 commit + 1 个 docs commit，ff 合入 main，打 `baseline-2026-06-11` tag。
- **主仓** `5606170..1cf0ec9`（13 commit，squash 单亲 `4a5210f`）：README 加 reSpeaker 语音集成行 + 社区贡献表重排（gamepad IK 遥操作 / D405 eye-in-hand TF）；⭐ 柔性夹爪 2 STEP 优化重导出；XT30U→XT60 外购件图 + 电源 BOM 行。**本地化**：用「无本地改动文件直接取 upstream 版 + 2 readme 只打上游 delta 补丁」精准法，powerstep 实拍图未上传注记完整保留；实测可推送历史 0 个 powerstep 大 blob。⚠️ 永久约束：主仓不可普通 merge upstream。
- **MotorBridge** v0.4.5 → `53fe6dd`（指针 `94d5812`）：ws_gateway `handle_damiao_state_many` 改先 `get_motor` 复用避免重复注册撞 ID。达妙核心+bindings 零改动、无版本 bump → **wheel 不用升**，仅更新指针。
- **reBotArm_control_py** → `0163c08`（指针 `f205358`）：追 develop 策略不变；develop 无新上游提交，但在 fork develop **cherry-pick 2 个 main bugfix**（`36d4346` URDF join3→joint3、`0163c08` get_joint_limits 改按 idx_q）。subagent 实测零冲突、对当前重力补偿/IK 实跑无影响（预防性）。fork develop 现比 upstream/develop 多 2 个自定义 commit。
- **ROS2 / StarArm_102**：无新（102 装配教程仍未发布）。
- ⚠️ **三个远端 push 待用户确认**：主仓 origin、MotorBridge fork origin/main、control_py fork origin/develop。硬件未验证（下次上电确认）；回滚点 `baseline-2026-06-07`，wheel 本次未动无需回滚。
- 详见 `上游更新记录/2026-06-11_同步详情.md`。
- ✅ 已 push：主仓 `9984906..23b7a3f` main + `baseline-2026-06-11` tag；MotorBridge fork `73443c7..53fe6dd`；control_py fork `062bef9..0163c08`。三端已对齐。

### 遥操作待办新增：纯仿真遥操作支线（手柄+IK）+ D405 eye-in-hand TF 参考
- 由上游同步进来的社区贡献（@danieldoradotalaveron-rb）引出讨论，记进 `遥操作与LeRobot待办.md`：
  - 新增「平行支线 3：纯仿真遥操作（无硬件学习路径，候选）」——手柄+IK 在 RViz 跑、仅仿真；定位为 102 物理遥操作前的预热 + 小红书选题；前提是先立 ROS2 Humble + 手柄 + 社区实验代码；标 🟡 候选先占位。
  - 支线1（摄像头）补 D405 eye-in-hand TF 交叉引用（跟 Gemini 2 装腕部同思路，ROS2 腕部视觉可借鉴）。

### 102 主动臂烧录：逆推 ID 对应 + 自建烧录指南
- 用户告知 **102 结构装配已完成（2026-06-11）**，问舵机烧录 ID 对应，官方无教程。
- **从代码逆出完整 ID↔关节↔B601 对应**（三处 102 代码 + 两仓 B601 配置交叉验证）：102 舵机 ID **0~6**（型号 rx8-u50，波特率 1M），对应 B601 达妙 **0x01~0x07**，规则 **102 ID = B601 ID − 1**（102 从 0、B601 从 1 编号）；两边都用 joint1-6+gripper 命名。
  - 102 来源：`Python_SDK/stararm102_ro.py`、`ROS2_HUMBLE/robo_driver.py`、`Lerobot/.../stararm102_leader.py`；B601 来源：`reBotArm_control_py/config/arm.yaml` + `gripper.yaml`。
- **查证教程出处**：Seeed 的 102 整臂 wiki（StarAI Arm in LeRobot）+ 仓内文档 **均无烧 ID 内容**（只有 `lerobot-calibrate` 校准）；**权威资料在 FashionStar 厂商 wiki**——`舵机离线ID设定、零位设置`（硬件设定板，长按按钮）+ `舵机上位机常用功能操作手册`（软件 GUI 写 ID + 改波特率）。⚠️ 一次只能连一颗舵机。
- **新建 `102主动臂烧录指南.md`**（根目录，跟 `装机烧录指南.md` 平行）：🟢 ID 对照表/参数 + ⚠️ 五个坑（**0-6 不是 1-7**、波特率 1M、单个烧、达妙/FashionStar 工具不通用、夹爪方向反）+ 烧录工具/流程/验证/参考链接（含 FashionStar wiki URL）。
- 交叉引用更新：`遥操作与LeRobot待办.md` §1.1（102 装配完成→进入烧录）+ §3.7（指向新指南）；`项目总览.md` 结构图登记新文档。
- 🟡 待实操确认：RA8 出厂默认 ID/波特率（FashionStar wiki 未写）、选定烧录工具、是否需显式标零点。

### 深度相机 Gemini 2 到货：建 YOLO 视觉抓取上手指南
- 用户告知 **Orbbec Gemini 2 已到货（未上电）**，定调"两条都跑、深度相机先弄"——先做官方 YOLO 抓取 demo（深度相机主用途；普通 USB 俯视相机排后）。
- 读透仓内官方教程 `视觉夹取_Demo.md` + 查 Orbbec 官方上手资料，理清完整流程。**关键事实**：
  - Gemini 2 **USB 供电**（USB-C 插 USB 3.0 口，无单独电源），先用 **Orbbec Viewer**（Windows）点亮验证硬件。
  - **demo 代码是独立仓** `github.com/Seeed-Projects/reBot-DevArm-Grasp`（≠ 本仓），用 `pyorbbecsdk`（需编译）+ conda env `rebotarm` + Eye-in-Hand 手眼标定（打印 10cm ArUco → `hand_eye.npz`）。
  - demo 跑 Ubuntu/Linux → ⚠️ 本机 WSL2 要 usbipd-win **同时透传相机+CAN 两设备**，USB3.0 深度相机带宽存疑，可能要权衡原生 Ubuntu。
  - 🟢 一致性：demo 克隆 vectorBH6/reBotArm_control_py **main**（含 idx_q 限位修复），跟本仓 fork develop 今天 cherry-pick 的修复一致，IK 限位都对。
- **新建 `Gemini2视觉抓取上手指南.md`**（根目录）：全景路线 + 先决准备 + 装环境命令 + 手眼标定 + 三段跑法 + 坑/FAQ + 待办 + 参考链接。
- 交叉引用更新：`遥操作与LeRobot待办.md` §3.9（到货进展 + 指向新指南）；`项目总览.md` 结构图登记。
- 🟡 待实操：选 WSL vs 原生 Ubuntu、打印 ArUco + 腕部支架、clone demo 仓跑通。

## 2026-06-12

### Arm102 LD + B601-DM LeRobot 真机联调：环境、校准、单轴 direct follow 验证

- **环境切换到 Seeed 官方教程路线**：WSL `Ubuntu-22.04` + Miniforge `~/miniforge3` + conda env `lerobot`，工作目录 `~/rebot_lerobot`。确认版本：`lerobot 0.4.4`、`lerobot_teleoperator_rebot_arm_102 1.0.0`、`lerobot_robot_seeed_b601 1.0.0`、`motorbridge 0.4.5`，`python -m pip check` 通过。
- **串口和校准状态**：当前 102 主臂为 CH340/COM11 → WSL `/dev/ttyUSB0`，B601 为 HDSC CDC/COM8 → WSL `/dev/ttyACM0`；校准文件已存在：`~/.cache/huggingface/lerobot/calibration/teleoperators/rebot_arm_102_leader/rebot_arm_102_leader.json` 和 `~/.cache/huggingface/lerobot/calibration/robots/seeed_b601_dm_follower/follower1.json`。
- **踩坑 1：PowerShell 和 WSL 命令混用**。Miniforge 安装时曾在 Windows PowerShell 里执行 `uname/source` 等 Linux 命令导致报错；已在手册里明确“先 `wsl -d Ubuntu-22.04`，再执行 Linux 命令”。
- **踩坑 2：LeRobot 0.5.x 与 Seeed 官方路线混装**。早期走过 Hugging Face 主线 `lerobot 0.5.2`，后切回 Seeed 教程的 `lerobot 0.4.4`；手册已记录不要混装，命令必须来自 `/home/pc/miniforge3/envs/lerobot/bin/`。
- **踩坑 3：官方 `lerobot-teleoperate` 能连接但不适合当前 WSL 实时遥操**。命令能连上 102 和 B601，但官方 `teleop_loop()` 每帧先 `robot.get_observation()`，对 B601 逐电机 `request_feedback()`；WSL USB/IP 下实测 `Teleop loop time ≈ 614ms (2Hz)`，并反复 `request_feedback failed: dm-serial write failed: Operation timed out`。结论：官方命令暂作对照，不作为当前主入口。
- **新增调试脚本**：`tools/lerobot_debug/arm102_to_b601_direct_follow.py`。它仍使用 Seeed 官方 102 leader 和 B601 follower 类，但控制循环跳过每帧 B601 feedback，直接读取 102 action 后向 B601 `send_action()`；支持 `--send-joints` 单轴测试和 `--invert-raw-joints` 在 102 原始角度裁剪前反向。
- **踩坑 4：2/3 轴“不动”不是电机坏，而是方向 + 限位裁剪**。B601 的 `shoulder_lift` / `elbow_flex` 限位为负区间，未反向时目标会被裁成 `0.00`。实测加 `--invert-raw-joints shoulder_lift,elbow_flex` 后 2/3 轴可动。
- **单轴验证结果**：
  - `shoulder_pan`：有效，`follower_target = -leader`
  - `shoulder_lift`：有效，但需要 `--invert-raw-joints shoulder_lift`
  - `elbow_flex`：有效，但需要 `--invert-raw-joints elbow_flex`
  - `wrist_flex`：有效，`follower_target = leader`
  - `wrist_yaw`：有效，`follower_target = leader`
  - `wrist_roll`：有效，`follower_target = -leader`
  - `gripper`：有效，`follower_target = -6 * leader`，并裁剪到 `[-270, 0]`
- **踩坑 5：`--send-joints` 只测试指定轴**。曾因只发 `shoulder_lift,elbow_flex` 误以为其他轴“不行”；已修脚本，`--send-joints` 模式下不会偷偷补发 `wrist_yaw=0`，并在手册中明确单轴测试方法。
- **文档同步**：更新 `LeRobot_Arm102LD_B601DM遥操作小白执行手册.md`、`遥操作与LeRobot待办.md`、`项目总览.md`，把当前推荐入口改为 direct follow。
- **下一步**：跑全轴小幅 direct follow，不要先用官方 `lerobot-teleoperate`：

```bash
python -u /mnt/d/Robot/reBot-DevArm/tools/lerobot_debug/arm102_to_b601_direct_follow.py --leader-port /dev/ttyUSB0 --follower-port /dev/ttyACM0 --fps 5 --invert-raw-joints shoulder_lift,elbow_flex
```

---

## 2026-06-13

### 0. 本地与远端对齐（拉另一台机的遥操作进展）
- 本地落后 origin/main **5 个 commit**（另一台机推的 Arm102→B601 遥操作进展：`tools/lerobot_debug/` 8 个调试脚本 + 执行手册 +859 行 + 待办/总览更新，无 submodule 指针变动）。
- `git merge --ff-only origin/main` 干净 ff 到 `c7b742e`，`git submodule update` 指针未变；本地 = 远端对齐。

### 1. 上游同步：仅 MotorBridge v0.4.5 → v0.4.6
- 例行检查 5 仓：主仓 Seeed / control_py(develop&main) / ROS2 / StarArm_102 **均无新**；只 **MotorBridge** 出 v0.4.6（`53fe6dd → 38b8a56`，4 commit）。
- ⭐ spawn 独立 subagent 复核 v0.4.6 达妙影响（碰了 motor_vendors/damiao，故必复核）：确认**低风险纯增量**——
  - `b4a839a` 达妙型号表新增 `4340_v20`/`4340X` 别名（DM4340 高转速变种 vmax20）：纯加一行 + display 函数，**现有 4340P/4340/4310 逐字节未动**；按 limits 反查无歧义（vmax 20 vs 10，差值远大于 tol）。
  - `13c6414` ws_gateway 浏览器 query 传 token：loopback 无 token 用法零影响，不碰达妙控制路径。
  - Python API 100% 兼容；版本 bump → 需升 wheel。
- 走 `sync/upstream-2026-06-13` 分支：提交 submodule 指针 `129eee0` + docs commit，ff 合入 main，打 `baseline-2026-06-13` tag。MotorBridge fork main ff `53fe6dd→38b8a56`（待 push）。
- **wheel 升 0.4.6**：Windows `E:\Python312` ✅（import + `__version__==0.4.6` + add_damiao_motor 验证）、WSL 系统 python3 ✅；⚠️ **LeRobot 环境（另一台机 0.4.5）待自升**——用户正用 0.4.5 调遥操作，建议调稳后再升（4340_v20 对其无影响）。
- 硬件未验证（风险极低）；回滚点 `baseline-2026-06-11` + wheel `pip install motorbridge==0.4.5`。详见 `上游更新记录/2026-06-13_同步详情.md`。

### 2. 新建 Ubuntu 双系统安装指南（为上原生 Linux 做准备）
- 背景：WSL 走 usbipd 转 USB，官方 `lerobot-teleoperate` 每帧逐电机读 feedback 往返延迟大（~614ms/2Hz + timeout）；官方闭环遥操作 + Gemini2/YOLO 抓取 demo 都要原生 Linux。结论：WSL 串口"能收但往返延迟大"，坑 3（官方路径慢）是 WSL 背锅，原生 Linux 可解；但坑 4/5（关节 invert 映射 / wrist_yaw 补 0）是软件映射问题，换系统也省不掉。
- 用户决定在**另一台 Windows 电脑（单块 SSD）压缩 C 盘装 Ubuntu 22.04 双系统**。
- **新建 `Ubuntu双系统安装指南.md`**（根目录）：确认下载 **Ubuntu 22.04.5 LTS**（对得上 Seeed lerobot 0.4.4）+ Rufus；从安全准备（备份/关 BitLocker/关快速启动）→ 磁盘管理压缩 C 盘 → Rufus 做启动盘 → 启动菜单键从 U 盘启动 → **"与 Windows 共存"安装**（⚠️ 别选 Erase disk）→ GRUB 选系统 → 装完接机器人（指回遥操作手册 + Gemini2 指南）+ 避雷速查表。
- 交叉引用：`项目总览.md` 结构图登记。
- 🟡 待用户提供：那台电脑品牌型号（对应启动键/BIOS）+ C 盘是否开 BitLocker + 给 Ubuntu 分多大。

### 3. 上游同步（当日第二次）：StarArm_102 d777473 → e8b871f
- 当日晚些再查上游，发现 **StarArm_102（102 主臂 SDK）上游推了 4 个新 commit**（上午查时还没有）；主仓/MotorBridge/ROS2/control_py 仍无新。
- ⭐ spawn 独立 subagent 复核：极低风险，全量 ff 镜像 upstream（垃圾仅进 fork、对象层面仅 ~248KB，主仓只存指针 SHA）。**纠正我 1 处误判**：所谓"6MB STL 垃圾"实际与现有 `ROS2_HUMBLE/src/` 同 blob SHA、git 去重，没那么大。
- **新增 Python_SDK 控制脚本（参考价值，非开箱即用）**：`stararm102_ro_hover.py`（悬停=角度静止检测+位置锁+推动切 unlocked 0x10 近似，**非真力矩**；电流估外力/pinocchio RNEA 路径都注释掉了 WIP）+ `stararm102_ro_button.py`（按键控制）+ `stararm102_ro_mode.py`（hover+重力补偿+过温保护，依赖 pinocchio 不能直接跑）；`stararm102_ro.py` 夹爪加 0~90° 限幅。
- 无删除破坏；对用户当前 `direct_follow` 遥操作工作流零影响（不走此 SDK）。⚠️ 含上游误提交垃圾（output.txt/rosbag/.vscode/重复 description），留 fork 历史不进主仓。
- 走 `sync/upstream-2026-06-13b` 分支，ff 合入 main，打 `baseline-2026-06-13b` tag。StarArm_102 fork main ff（待 push）。回滚点 `baseline-2026-06-13`。详见 `上游更新记录/2026-06-13_同步详情.md` 补充段。

### 4. 上游检查（当日第三次）：StarArm_102 上游重写历史 re-mirror + control_py main 评估不同步
- 再查上游，StarArm_102 和 control_py main 有新动静（主仓/MotorBridge/ROS2 无新）。⭐ 并行 spawn 2 个 subagent 复核，**都推翻了我的初判**。
- **StarArm_102 `e8b871f → e61f34e`（re-mirror，指针 `e55a60c`，tag `baseline-2026-06-13c`）**：上游作者把我上午刚同步的 4 个 commit **重写压缩成更干净的 `e61f34e`**（已分叉非 ff）。新增官方 `Lerobot/lerobot-stararm102/` 适配器包（HD=leader/FL=follower 角色对 + 官方标定 joint 方向/范围，参考价值高，但 102 同构非 B601 异构不能直接用）+ 清垃圾（output.txt/rosbag/.vscode）+ button/mode 合并进 ro.py。净瘦身无大 blob，功能不丢，对 direct_follow 零影响。执行 fork `reset --hard` + **force-push**（内容都是上游自己提交，可接受）。用户拍板"对齐"。
- **control_py main 8 commit（`893f095→b338d8b`）：❌ 评估后不同步**。subagent 复核：不是"RS+STL"那么简单，是**破坏性 API 重构**（RobotArm→RebotArm、删 arm.py/arm.yaml、重写所有 example）；DM 改进（safe_home/MIT 带重力）**全寄生新 API 无法干净 cherry-pick**；硬摘要拖 ~70MB RS STL + 跟 idx_q cherry-pick 冲突 + 把重力补偿 kp=0 改成 2.0 改手感。DM URDF 改动只是 mesh 路径重写零数值影响。**维持 develop 0163c08 不动**（追 develop + develop 无新=已最新）。用户拍板"跳过"。
- 🟡 RS 版未来若上：那套重构（含 RS URDF/STL）届时才相关，正确做法是等它合进 develop 后整体同步，而非现在 cherry-pick。详见 `上游更新记录/2026-06-13_同步详情.md` 补充2。
### 5. Arm102→B601 direct follow 全轴遥操确认通过 + 一键启动脚本入仓

- 用户将电脑、102 主臂、B601 从臂重新上电后，请求重新跑遥操。
- Windows `usbipd list` 确认当前设备：
  - `1-6 1a86:7523 USB-SERIAL CH340 (COM11)` = 102 主臂
  - `1-7 2e88:4603 USB 串行设备 (COM8)` = B601 从臂
- WSL 初始为 stopped；启动 WSL 后执行 `usbipd attach --wsl --busid 1-6` 和 `usbipd attach --wsl --busid 1-7`，两个设备变成 `Attached`。
- 用 root 方式加载/授权串口，避免后台 `sudo` 等密码卡住：

```powershell
wsl -d Ubuntu-22.04 -u root -- bash -lc "modprobe ch341 || true; modprobe cdc_acm || true; chmod 666 /dev/ttyUSB* /dev/ttyACM* 2>/dev/null || true; ls -l /dev/ttyUSB* /dev/ttyACM*"
```

- 确认 WSL 串口：
  - `/dev/ttyUSB0` = 102 主臂
  - `/dev/ttyACM0` = B601 从臂
- 跑 102 只读短测，`read_raw_angles.py` 能连续输出 `shoulder_pan / shoulder_lift / elbow_flex / wrist_flex / wrist_yaw / wrist_roll / gripper`。
- 启动全轴 direct follow：

```bash
python -u /mnt/d/Robot/reBot-DevArm/tools/lerobot_debug/arm102_to_b601_direct_follow.py --leader-port /dev/ttyUSB0 --follower-port /dev/ttyACM0 --fps 5 --invert-raw-joints shoulder_lift,elbow_flex
```

- 用户确认：这次遥操效果很好。阶段结论更新为 **Arm102→B601 direct follow 全轴基础遥操已通过**。
- 新增 PowerShell 一键启动脚本：

```text
tools/lerobot_debug/start_direct_follow_wsl.ps1
```

脚本内容：进入 WSL、激活 `lerobot` conda 环境、进入 `~/rebot_lerobot`、执行全轴 direct follow 命令，并保留窗口方便 `Ctrl+C` 停止和查看输出。

当前推荐启动命令：

```powershell
powershell -ExecutionPolicy Bypass -File D:\Robot\reBot-DevArm\tools\lerobot_debug\start_direct_follow_wsl.ps1
```

注意：该脚本默认 USB 已经 attach 到 WSL；如果重启后没有 `/dev/ttyUSB0` / `/dev/ttyACM0`，先按手册重新 attach USB。

---

## 2026-06-18

### 1. 三仓上游同步：MotorBridge v0.4.7 + ROS2 9 commit + 主仓 5 文档（用户拍板"全部同步到最新"）

- **起点对齐检查**：本地已提交内容 == origin/main（0/0），仅 2 个未提交本地文件（`tools/lerobot_debug/start_direct_follow_wsl.ps1` 改动 + `set_zero_base.py` 新文件），本次同步**不混入**（commit 分层）。
- **网络**：直连 GitHub 被挡（443 连不上），经本地代理 `127.0.0.1:7890` fetch 主仓 + 4 submodule 上游。
- ⭐ **并行 3 个 subagent 分仓复核**（MotorBridge / ROS2 / 主仓），全部完成、纠正/确认初判后才执行。

**各仓结果**：

| 仓库 | 变化 | 处置 |
|---|---|---|
| MotorBridge | `38b8a56`(v0.4.6)→`2b7b350`(v0.4.7) 3 commit | ✅ 升级，指针 `1bf9665` |
| reBotArmController_ROS2 | `c6a4e68`→`a61efe4` 9 commit | ✅ 升级，指针 `f7c9645`（含 63MB RS STL，用户确认接受） |
| Seeed 主仓 | 真新增 5 commit（剔除 squash 重复） | ✅ squash 单亲 `63a3cfb` |
| reBotArm_control_py | develop 无新 | — |
| StarArm_102 | 无新 | — |

- **MotorBridge v0.4.7（⭐ 对症遥操作超时）**：`dadfe8d` dm-serial 串口超时预算 **1ms→10ms**；`bbcca2d` 达妙模式切换加固（写寄存器等 `0x55` write-ack 3 次重试 + `ensure_control_mode` 共享超时预算 + 切换前后持位 + store_parameters 自动 disable）。达妙 +约 600 行新单测，Python API 100% 兼容。**直接对症** 06-13 遥操作的 `dm-serial write failed: Operation timed out` / `clear_error timed out`。⚠️ 行为变更：写寄存器现等 write-ack，若 DM4340P/4310 固件不回 `0x55` 会从静默成功变超时报错——**待下次上电冒烟测**，若见 `write ack not received` 则回退 0.4.5。
- **ROS2 a61efe4（B601-RS 为主线）**：唯一 DM 相关 `d943b8f` 修 `rebotarm_hardware.yaml` 中 `models.dm.gravity_compensation` 的 kp/kd（误填 MIT 数组 `[120,120,120,18,18,18]`/`[8,8,8,2,2,2]` → 标量 `2.0`/`1.5`，已确认入树）；其余全是 RS 版 URDF/MoveIt2/夹爪 + 30 个 RS STL（63MB，DM 实操零价值）。⚠️ 破坏性变更（删 `JointVelCmd.msg`/`SetMode.srv`、launch 参数改名、config 整合）本仓未进 ROS2 阶段不消费，**当前零影响**，登记待进 ROS2 阶段复核。
- **主仓 5 commit（squash 单亲法）**：边界 `1cf0ec9`（06-11 squash 已吸收）三重验证确认；真新增 = README×5 文本（RS 五种套件选项 + DM/RS 参数对比 + 48V 电源推荐 + banner 换 `RS5_56.png`）+ readme_zh 1 行（电源京东链接 URL，**保留本地 94MB 警告块**）+ `media/RS5_56.png` 7.75MB（可推送）。验证 `git rev-list --objects HEAD` **powerstep 对象 = 0**，无大 blob 进可推送历史。

### 2. wheel 全部升级到 0.4.7（PyPI 已发布）

| 环境 | 升级 | 验证 |
|---|---|---|
| Windows PATH python | 0.3.7 → 0.4.7 | import OK |
| WSL 系统 python3 | 0.3.7 → 0.4.7 | import OK |
| ⭐ WSL conda `lerobot`（遥操作环境） | 0.4.5 → 0.4.7 | import OK，Controller/Mode 可用 |

- 注：文档曾记 Windows wheel 在 `E:\Python312`，本机不存在该路径，实为 PATH python（印证项目跨两台机，wheel 记录可能是另一台的）。
- 回滚：任一环境 `pip install motorbridge==0.4.5`（lerobot 环境）/`==0.4.6`。

### 3. 同步收尾

- sync 分支 `sync/upstream-2026-06-18`（3 个分层 commit）合入 main，打 `baseline-2026-06-18` tag。
- fork push（ff）：`fanhao375/motorbridge` `38b8a56→2b7b350`；`fanhao375/reBotArmController_ROS2` `c6a4e68→a61efe4`。
- 新建 `上游更新记录/2026-06-18_同步详情.md`。
- 🟡 **下次上电遥操作 = v0.4.7 write-ack 行为冒烟测**：重点看 `dm-serial write timeout` 是否减少 + 是否出现 `write ack not received`。
- 那 2 个未提交本地文件已分层提交（见下节 4），不混入上游同步。
- ⚠️ `复刻基线维护原则.md` §3 各仓"当前状态"行（仍记 MotorBridge v0.3.9 / 2026-05-28）已滞后多轮，按该文件"更新需双方确认"规则未擅自改。

### 4. 本地遥操作工具提交（一键脚本升级 + 底座设零工具）

承接上游同步后，把会话前晾着的 2 个本地工具文件分层提交并 push：

- **`40e42db` 一键遥操脚本升级**：`tools/lerobot_debug/start_direct_follow_wsl.ps1` 从"只启动遥操作"升级为端到端一键——按 VID:PID 解析当前 BUSID（Arm102 CH340 `1a86:7523` / B601 桥 `2e88:4603`，换 USB 口不写死）→ 拉起 WSL → `usbipd attach` 两个串口 → `modprobe ch341/cdc_acm` → 轮询等 `/dev/ttyUSB0`+`/dev/ttyACM0` 就绪 → `chmod 666` → 启动 direct follow。全中文提示 + 失败排查指引。
- **`e992cee` 新增 B601 底座设零小工具**：`tools/lerobot_debug/set_zero_base.py`（51 行）只对底座 shoulder_pan（id `0x01/0x11`, 4340P）操作，**全程 `disable_all` 不 enable**（避免连接时底座先跳）。`disable` 模式松力 + 读当前角度；`setzero` 模式松力 + `set_zero_position` 设当前物理位置为新零点 + 读结果确认接近 0。
- 二者均为 6-18 当日本地实操产物（非上游），单独提交、不进 baseline-2026-06-18 同步范围。

### 5. 决定就在本机上 Ubuntu 双系统 + 前期准备实测

- 用户结论：**WSL 虚拟机 usbipd 串口延迟还是不行，最终上原生 Linux**——且改为**就在 D:\Robot 这台遥操作机上装双系统**（原指南设想的是另一台）。
- 直接读硬件做前期体检（只读，未改系统）：
  - 组装台式机，主板 **Intel SKYBAY**，BIOS 5.12(2020)，**UEFI + GPT**，单块 **477G SATA SSD**。
  - 分区：EFI/MSR + **C: 225G(剩165G)** + **D: 251G(剩207G，盘尾分区)**；页面文件在 **C:**（压 D: 不被挡）；D: 仅用 ~44G（**WSL 占 40G**，上原生后可回收）；内存 16G。
  - 快速启动**开着**（HiberbootEnabled=1，待关）；BitLocker 读不到需管理员确认。
- **定制方案**：从 **D: 末尾压 150G**（`153600`，盘尾未分配最干净，C: 不动）；Rufus GPT/UEFI；启动键 **F10**(Intel 主板菜单)/F2-Del(设置)；共存安装；conda 装 `motorbridge==0.4.7`。
- 文档：`Ubuntu双系统安装指南.md` 新增"★ 本机配置 & 定制方案"节 + §10 待办勾掉已实测项 + §8.3 wheel 对齐 0.4.7。
- ✅ 装前两雷已排（2026-06-18 用户管理员实测）：**BitLocker 没开**（版本=无/完全解密/保护关闭/0.0%）+ **快速启动已关**（reg HiberbootEnabled=0）。盘可安全压。
- ✅ **D 盘已压**（2026-06-18，管理员 `Resize-Partition -DriveLetter D -Size (Size-150GB)`）：D: 251.5→101.5G（最小可缩到 44.8G，余量充足），盘尾空出 **150G 未分配**，位置在盘最末尾、留给 Ubuntu，未格式化。
- ✅ ISO 已下：`ubuntu-22.04.5-desktop-amd64.iso`（4.4G，desktop 版）。
- ✅ 启动盘制作中/已设好：Rufus 4.14，设备 **X3CPRO (E:) 32G** U 盘，引导=该 ISO，**分区类型 GPT + 目标系统 UEFI(非 CSM)** 确认无误（卷标 Ubuntu 22.04.5 LTS amd64 / FAT32 默认）；点开始写盘。
- 🟡 下一步（待用户）：Rufus 完成 → 重启**开机狂按 F10**（Intel 主板启动菜单）→ 选 **"UEFI: X3CPRO"** → GRUB 选 "Try or Install Ubuntu" → 进安装向导，走到**"安装类型"屏停下拍照确认**选"与 Windows 共存"（⚠️ 别选 Erase disk）。F10 不行试 F12/F8/Esc/Del-F2 进 BIOS。
- 远程访问方案（异地，装完再配）：主力 **Tailscale + SSH**（组虚拟局域网，异地变同网段）；图形界面加 **NoMachine / 向日葵 / RustDesk**。⚠️ 实时遥操作必须人在现场（手摆主臂），远程只用于启动/监控/采数据/训练/调试。已写入 `Ubuntu双系统安装指南.md` §11。

## 2026-06-19

### 1. Ubuntu 双系统装成功（研华 MIC-7700Q 机器人机）
- ✅ **装成功**：研华 **MIC-7700Q** 工业机（非当初设想的 Intel SKYBAY 组装机；MIC-7700 本就是 SKYBAY 平台，名字对得上）。**从 BIOS「Boot」标签**把 U 盘 `UEFI: Lenovo UFD X3CPro` 设第一启动（F10 启动菜单这台不灵，直接进 BIOS 设 Boot 顺序最稳）→ GRUB "Try or Install Ubuntu" → 安装向导选「**与 Windows Boot Manager 共存**」→ 写盘确认窗只「**第 5 分区设为 ext4**」（盘尾 150G 新建，C/D/EFI 未动，安全）→ 用户 `pc`/`admin123`（用户名 `pc` 正好对上手册 `/home/pc/...` 路径）。
- ✅ 向日葵远程装好（Wayland 黑屏坑：`/etc/gdm3/custom.conf` 取消注释 `WaylandEnable=false` 切 Xorg）。

### 2. 联网代理踩坑一整天：Clash 不稳 → 换 v2rayA 才通终端代理
- **核心教训（已写入 `Ubuntu双系统安装指南.md` ★ 节）**：Linux 上**浏览器走系统代理、终端 curl/npm 不读系统代理**，必须 env 变量或透明代理。
- Clash Verge 反复切系统代理/TUN 把核心状态搞坏（已知 bug）+ 节点不稳（英国 IEPL 761ms 丢包）+ OpenSSL 3.0 严格 → 间歇性 `unexpected eof`（curl/Xray 已知问题，浏览器自动重试所以没事）。
- ✅ **换 v2rayA**（`installer_debian_x64.deb` + 现成 v2ray-core + 导 Trojan 通用订阅）+ 设「**透明代理=启用:不进行分流**」+「**防止DNS污染=转发DNS请求**」→ 终端代理通（`curl -I api.anthropic.com` 出 `HTTP/2 403`）。节点选低延迟美/日，curl 加 `--retry 5 --retry-all-errors` 穿抽风。

### 3. Claude Code + git 上 Linux
- ✅ **Claude Code 装上**：`claude.ai/install.sh` 被**地区拦**（App unavailable in region），但 `api.anthropic.com` 通 → 走 **npm 绕开 claude.ai**：NodeSource 装 Node 20 + npmmirror 装 `@anthropic-ai/claude-code`（`added 2 packages`）。🟡 `claude` 登录待处理（claude.ai 被拦，OAuth 可能要换节点/API key）。
- ✅ **git**：`sudo apt install -y git`（apt 已是清华镜像，不用代理）。
- 🟡 下一步：Claude Code 登录 + 装遥操作环境（Miniforge+conda lerobot+motorbridge 0.4.7）+ clone 机器人项目到 Linux。

## 2026-06-20

### 原生 Linux 跑通 Arm102→B601-DM 遥操作（60Hz 全 7 轴，根治 2/3 老问题）
接 06-19，在原生 Ubuntu（研华 MIC-7700Q，用户 `pc`）从零搭好遥操作环境并跑通。**核心收获：WSL 下官方 `lerobot-teleoperate` 卡 2Hz + 反复 `request_feedback timeout` 的病根就是 usbipd 转发，原生 Linux 串口直连后彻底消失，官方命令实测稳定 60Hz。**

- **环境**：clone 本仓 + `git submodule update --init`；miniforge → conda 环境 `lerobot`（py3.10）；clone Seeed 三仓到 `~/rebot_lerobot`（lerobot 0.4.4 / teleop-102 1.0.0 / robot-b601 1.0.0）；装 motorbridge 0.4.7 + smart-servo 0.0.4 + fashionstar 1.3.12 + python-can。
  - **pip 大坑**：本机 USB-WiFi（RTL88x2bu）直连清华镜像反复大文件抽风掉线；**走代理 127.0.0.1:7897 + 官方 PyPI 最稳**（CPU torch 175MB 一把过）。有 RTX A2000 但无驱动 → 装 **CPU 版 torch 2.7.1 + torchvision 0.22.1**（`download.pytorch.org/whl/cpu`），跳过 ~5GB CUDA wheel（遥操作不用 GPU）；torchvision 必须同为 cpu 版否则 `torchvision::nms does not exist`。适配器要 `--no-deps` 装（否则 `lerobot>=0.4` 把 torch 拽升 2.10 CUDA 915MB）。evdev 需 `sudo apt install build-essential python3-dev linux-libc-dev` 才能编译。
- **硬件接入**：原生 Linux 免 usbipd，插上即 `/dev/ttyUSB0`(102 CH340) + `/dev/ttyACM0`(B601 达妙桥)。⚠️ **CH340 被 brltty 抢占**导致 ttyUSB0 不出现 → `sudo apt remove -y brltty` 重插即好（Ubuntu 经典坑）。用户不在 dialout 组，每次 `sudo chmod 666` 两口。
- **校准**：新机器无校准缓存，重建 follower（`seeed_b601_dm_follower/follower1`）+ leader（`rebot_arm_102_leader`），均"摆零位+闭夹爪+回车"。被动对比 `b601_passive_compare.py` 实测**全 7 轴 delta≈-0.01°**，零位完美对齐（B601 电机固件零点跨机器保留）。**全程零 timeout**。
- **2/3 轴（shoulder_lift/elbow_flex）三连修**（4340P 大臂；这俩在 WSL 时就有问题）：
  1. **不动 → 取反**：102 这两轴物理装反，官方映射裁到 ~0。在 `rebot_arm_102_leader.get_action` 解缠后对这俩轴 `position=-position`（复刻 direct_follow 的 `--invert-raw-joints`）→ 官方 60Hz 也全轴跟手。
  2. **过 90° 跳回 0（"掉力/乱跳"真凶）→ 量程对称**：日志铁证 `raw=80.6 → unwrap=-279.4 k=1 → 跳到0`。`_round_to_valid_range` 的窗口=量程中点±180，elbow 默认 `(-200,1)` 中点-99.5→窗口上界仅 **80.5°**，过它就 ±360 翻转。改对称 `elbow_flex(-200,200)` / `shoulder_lift(-170,170)` → 窗口 ±180，实测走到 125.9° 平滑不翻（k 全 0）。**不是过流/过温保护**（`status_code` 全程=1 没掉力，是解缠翻转让从臂猛追错误目标）。
  3. **限速兜底**：follower `max_relative_target None→12`（°/帧@60Hz=720°/s），吃掉残留单帧坏读数，正常手速不受影响。
- **补丁固化**：三处改的是 `~/rebot_lerobot`（Seeed 克隆，不在本仓 git，重装会丢）→ 存进仓库 `tools/lerobot_native_linux/`：`apply_patches.py`（幂等重打）+ `patches/*.patch` + `start_teleop.sh` + `README.md`。重装后 `python tools/lerobot_native_linux/apply_patches.py` 即恢复。
- **遗留（非故障）**：满伸展高负载点 2/3 力矩仍高（~18），电机不掉力不跳，是真实重力负载；要再降抖动方向是重力补偿/MIT 模式（`software/reBotArm_control_py` 有例程），属另一条线。记忆新增 `project-native-linux-lerobot-env`。

## 2026-06-21

### 上游检查 + 主仓同步（RS 版电源资料，squash 单亲，大图 gitignore）
原生 Linux 新克隆，给 5 仓首配 upstream remote（走代理 7897 fetch）后例行检查。**只有主仓有新**：上游 `..0522186` 6 条 commit（06-18~06-19）**全是 RobStride(RS)版**——RS 电源组装教程 + 外壳 STEP×3 + 外购件图 + 多语言 README（Pinocchio 适配 wiki 链接 / B601-RS 的 ROS2 集成 + 视觉抓取 demo 链接 / RS 套件选项）。**DM 版功能代码零改动**，RS 硬件未购、当前价值低。

- **决策**：用户拍板"全量同步但大图 gitignore"（选项 B）。按 05-31 既定永久约束（主仓不可普通 merge upstream）走 **squash 单亲**。
- **冲突**：7 个 README 冲突 → 顶层 5 个取上游（纯文档更新无自定义）；DM readme×2 取本地（保住「94MB 图本地化」警告块，上游本范围未改 DM readme）。
- **⚠️ 大图坑**：`git merge --squash` 把上游**追踪**的两套 powerstep 装配实拍图都拽进暂存区——RS 42MB + **DM 94MB**（本 fork 一贯不上传），全部 `git restore --staged` 撤出、本地磁盘保留。`.gitignore` 新增 RS powerstep 忽略行。RS readme 加同款警告块。
- **安全验证**：`git rev-list --objects origin/main..HEAD` → **powerstep 推送对象=0**，最大 blob 仅 1.2MB（RS 外壳预览图），实际提交 ~7.4MB。
- **4 个 submodule 全 0 落后无更新**（MotorBridge v0.4.7 / ROS2 a61efe4 / StarArm_102 e61f34e / control_py 0163c08）。⚠️ control_py 上游把 `develop` 拆成了 `develop-dm`（我们 pin 0 落后）/`develop-rs`（+17 RS）/`main`（+23 破坏性重构，06-13 已决策不追），DM 相关 pin 不动。
- 合并 `sync/upstream-2026-06-21` → main（ff），打 `baseline-2026-06-21`，push origin/main + tag。详见 [`上游更新记录/2026-06-21_同步详情.md`](./上游更新记录/2026-06-21_同步详情.md)。

## 2026-06-22

### 上游检查：无 DM 相关更新（control_py 仅动了不追的分支）
例行 fetch 5 仓 upstream。**4 仓全无更新**（主仓 `0522186` / MotorBridge v0.4.7 / ROS2 `a61efe4` / StarArm_102 `e61f34e`）。**control_py 有动静但全在不追的分支**：`main` +1（`03d6802 add EN`，破坏性重构线文档）+ 新增 `win` 分支（7 个 `Update README_*` 文档 commit）。⚠️ **上游把 `develop` 重置了**：昨天 `develop=5537201`（我们 pin 含），今天指到 `8cf1a44`＝`develop-rs`，即上游把 `develop` 改成了 RobStride 线。**`develop-dm`（达妙线）未动**（`a012a40`，仍含在我们 pin `0163c08`）。**结论：DM 零更新，submodule pin 不动**——且此事印证 06-21 "保持追 fork 自己的 develop、不盲目同步上游 develop" 的决策（上游 develop 现已变 RS 线，我们 fork develop 冻结未被波及）。下次触发：develop-dm 出现新 commit，或主仓/MotorBridge 有 DM 相关更新。

### Gemini 2 深度相机 Windows 点亮验证通过 + 主线方向定调
- ⭐ 原生遥操作 60Hz 已跑通（见 06-20），用户拍板**主线下一步走"装摄像头 + 采数据"**（训 AI），YOLO 深度抓取 demo 后置。
- **Gemini 2 在 Windows 用 Orbbec Viewer 点亮验证通过**：彩色/深度/红外/IMU 四路全正常，相机硬件 OK。⚠️ 当时插 USB 2.0（日志 `fps too low`，depth 仅 2fps/color 22fps），**实际采数据须插 USB 3.0**。
- **相机方案确认**：Gemini 2 装腕部、用其 **RGB 流当 LeRobot 腕部相机** + 再买 1 个**普通 USB 摄像头当俯视**（深度先放着）；腕部/俯视天然不同型号，自动避开同型号 USB 路径冲突坑。
- 🟡 下一步：买 USB 俯视摄像头 → Linux 装腕部支架(`D435_Gemini2_Mount.step`) + 装 pyorbbecsdk + 再点亮 → `lerobot-record` 采数据。详见 `遥操作与LeRobot待办.md` §3.9（2026-06-22 进展）。

## 2026-06-24

### 上游同步：主仓 DM 供电件装配更新 + MotorBridge v0.4.8（control_py 破坏性重构评估不合）
例行检查 5 仓 upstream。**3 仓有新**：主仓 + MotorBridge 同步，control_py 评估不合，ROS2/StarArm_102 无需动。按 memory 规则 spawn 2 个独立 subagent 复核 control_py + MotorBridge。

- **① 主仓 Seeed `0522186..67d233c`**（实质 `de86d01`，⚠️ `1cf0ec9..` 会重列已 squash 的 06-18 内容＝squash 重列假象，真锚点是 06-21 同步点 `0522186`）：**DM 供电件装配步骤更新**——3D 打印件 STEP→stp 格式迁移（删 3 旧 .STEP 新增 3 .stp）、打印件预览图 3 张更新（最大滑盖图 682KB→2.28MB）、readme 图引用 jpg→png + 螺丝改 304 不锈钢 + 加六角螺母 M3×2.5；RS README 修电源章节 BOM。
  - **squash 单亲**（遵 05-31 约束）：7 冲突→3 预览图取上游（已 track 缩略图非大图）+ 4 README 取上游全文再插回「powerstep 本地化警告块」（DM 措辞 STEP→STP）。
  - **大图坑**：merge 又把 DM 94MB + RS 42MB powerstep 实拍图拽进暂存（RS 是 squash 重列再现）→ 全 `restore --staged` 撤出、gitignore、磁盘留。
  - **跟随上游删旧 .STEP**：merge 因 merge-base 不含旧 STEP 判为"我方新增"未暂存删除，手动 `git rm` 3 个旧 .STEP（readme 已只指 .stp）。
  - **安全验证**：`origin/main..HEAD` powerstep 对象=0，最大 blob 2.28MB（预览图）。提交 `fdcdc10`。
- **② MotorBridge v0.4.7 → v0.4.8**（4 commit，fork main ff `123a6ad`，指针提交 `a41410d`）：⭐ subagent 逐字节复核——`19e81a7` 纯 ci/rustfmt；`43c341a` ws-gateway 单电机定向（**仅 ws_gateway 层，我们走 native API 零影响**）；`29305d5` "align DM naming" **实为 RobStride 状态字段标签对齐，非达妙改名**（0 行 damiao 代码，`DAMIAO_MODELS`/`add_damiao_motor` 零改动）；Python API 100% 兼容。**风险低、对达妙零实质影响**。⏳ wheel 0.4.8 升级待用户跑（纯追新无收益）。
- **③ ⚠️ control_py：develop 被上游强制重写 `5537201→8cf1a44`**，把 06-13 评估过的**破坏性 API 重构合进 develop**（且更彻底）。⭐ subagent 实证复核：`RobotArm→RebotArm`+**JointGroup 架构**（`arm.mit()`→`arm.send_mit()` 语义级破坏）、删 `arm.py`/`arm.yaml`、**+63MB RS STL**+52 pyc 进历史、重力补偿**运行时 kp 0→2.0**+末端 mass 0.55→0.45（改已验证手感）、本地 cherry-pick(idx_q/joint3)已冗余；但**当前遥操作走 LeRobot `RebotArm102Leader` 插件、不依赖此 API**。**决策：维持 `0163c08` 不动暂不合**——DM 净收益仅 1 行 mass，不值 63MB+破坏性重写+改手感。
- **④ ROS2** `a61efe4`：upstream/main 推到 a61efe4 但我们指针**已是 a61efe4**（已含最新），无需动；**StarArm_102** `e61f34e` 无新。
- 合并 `sync/upstream-2026-06-24` → main（ff），打 `baseline-2026-06-24`。✅ 已 push：origin/main + tag + MotorBridge fork。详见 [`上游更新记录/2026-06-24_同步详情.md`](./上游更新记录/2026-06-24_同步详情.md)。

## 2026-06-27

### 撤销 max_relative_target 限速补丁（遥操作延时修复，固化）
06-25 实测：第 3 个补丁 `max_relative_target=12`（限速安全网）那条代码路径**每帧读 7 个电机状态 + 把目标钳制在"当前±12°"**，导致从臂明显延时；"过90跳回0"的根因已被补丁 2（leader 量程对称）在源头修掉，限速没必要。**恢复上游默认 `None`** → 延时明显改善，用户确认。`apply_patches.py` 移除该补丁（剩 2 个）、README 同步、删 `patches/03_follower_max_relative_target.patch`。

### ⭐ 阶段 5 数据采集跑通：相机就位 + lerobot-record 采到 23 条干净视觉演示
本机定位明确：**只采数据，训练在另一台 5060Ti 16G**（这台不用装 GPU 驱动）。

- **相机最终就位**：Insta360 Link 2 俯视(`by-id`，1280x720 MJPG) + Gemini 2 RGB 腕部(`by-path`，640x480 MJPG)。用 rerun 实时预览(`rr.init(spawn=True)` 循环 log 帧，cv2 headless 不能 imshow)边看边调好构图——601 夹爪+操作区居中、积木与盒子两视角都清晰。
- **`lerobot-record` 全链路跑通**，踩平 6 个非显然坑（已固化进 [`tools/lerobot_native_linux/采数据_lerobot_record.md`](./tools/lerobot_native_linux/采数据_lerobot_record.md)）：① 相机 warmup 超时(Insta360 首帧 2.7s，给 `warmup_s:6`)；② 双相机 USB2.0 带宽抢占→Gemini 强制 `fourcc:MJPG`；③ Insta360 MJPG 只支持 1280x720；④ `display_data=true`+大图写盘拖到 14fps→关 display + `num_image_writer_processes=2`→25fps；⑤ `video_encoding_batch_size>1` 触发 `NoneType` bug→保持默认；⑥ ⚠️**`--dataset.video=false` 在这版会剔除所有相机特征(只留关节)，不是存 PNG**——要画面必须 `video=true`（曾误用录了 10 条无图数据作废重录）。
- **固有限制**：`video=true` 每条之间有 20-80s 编码冻结(读 PNG 编 MP4 的 I/O，CPU 扛不动实时)，冻结期遥操作停摆。缓解=每条录短(任务做完按 `→` 提前结束)；判别法=**601 跟手=在录，601 卡住=在编码别动**；后台跑时由 Claude 盯日志喊"🟢录/🔴停"节奏。
- **成果**：数据集 `fanhao375/block_in_box`「把积木放进盒子」，录 28 条→验收(按 action/state 幅度判废)→`lerobot-edit-dataset delete_episodes` 删 5 条空条(主臂没动)→**23 条干净有效**(10125 帧 30fps，俯视+腕部双路视频)。打包 `~/block_in_box_dataset.tar.gz`(455MB)待拷训练机；原始 28 条备份在 `block_in_box_old`。⏳ 下一步：搬训练机跑 ACT；23 条偏少，效果不足再续录(`--resume=true`)。
- 注：数据集都在 `~/.cache/huggingface/lerobot/`，**不入仓**(大文件)，本仓只记流程文档。

### ⭐ 训练端环境搭建（5060Ti Windows 机 WSL2）+ 暴露数据损坏阻塞
GPU 分工的「训练」端：在 5060Ti 16G 这台 Windows 机的 **WSL2 Ubuntu-22.04** 配 LeRobot 训练环境跑 ACT。环境跑通、GPU 可用、数据能读，但烟雾测试暴露**数据集视频损坏**，训练受阻待修。

- **最终可用环境**（venv `~/lerobot-venv`，系统 Python 3.10.12）：`torch 2.10.0+cu128` + `torchvision 0.25.0+cu128`（Blackwell sm_120/CUDA12.8）+ `lerobot 0.4.4` + `torchcodec 0.10.0` + `av(pyav)`。验证 `torch.cuda.is_available()=True`，device=RTX 5060 Ti capability (12,0)。
- ⭐ **版本对齐三角（核心踩坑）**：
  - **lerobot 版本 ↔ 数据集格式**：数据是 **v3.0**（`meta/tasks.parquet`）。`lerobot 0.3.2`=v2.1(找 `tasks.jsonl`)读不了；`0.5.1` 需 **Python 3.12**(我们 3.10)用不了；**`0.4.4` = CODEBASE_VERSION v3.0 且 Python>=3.10** → Python 3.10 下读 v3.0 的唯一选择。
  - **lerobot 0.4.4 ↔ torch**：0.4.4 约束 `torch<2.11` → 不能用 2.11，降 **2.10.0+cu128**（仍支持 Blackwell）。（之前钉死 torch 2.11 把 lerobot 一路压回 0.3.2 = 读不了 v3.0 的连环坑）
  - **torchcodec ↔ torch**：必须配对。0.14(配 torch2.12/CUDA13)挂 `libnvrtc.so.13`；**0.10(配 torch2.10/CUDA12)OK**。
- ⭐ **网络/镜像坑**：
  - 直连 `files.pythonhosted.org` 被限速 **18kB/s**（pillow 下 7 分钟）→ pip 改**阿里云镜像**(`~/.config/pip/pip.conf`，index=aliyun+extra=tsinghua)秒下。
  - torch cu128 走 `download.pytorch.org/whl/cu128`（镜像没有）；大件下完进 pip http 缓存(3.9G)**复用零重下**。
  - ⚠️ **pip.conf 的清华 extra-index 会渗进 torch 安装**把 cu128 带偏成通用版(torch 2.12.1 无+cu128) → torch 那步必须 `PIP_CONFIG_FILE=/dev/null` + 钉死 `torch==2.10.0+cu128`。
  - HF 走 **`hf-mirror.com` 直连**(`HF_ENDPOINT`，写进 `~/.wsl_net_env.sh`)，比 VPN 稳；Clash 代理做 `proxon`/`proxoff` 按需（节点抽风时 SSL eof）。WSL 用 Windows Clash 需 CFW 开「允许局域网」，经 `172.18.192.1:7890`。
- ⭐ **训练命令（ACT）**：`HF_HUB_OFFLINE=1 lerobot-train --dataset.repo_id=fanhao375/block_in_box --policy.type=act --policy.device=cuda --dataset.video_backend=pyav --batch_size=8 --steps=N --wandb.enable=false`。**视频后端用 pyav**（torchcodec 在多进程 dataloader 的 fork worker 里不友好）。HF_HUB_OFFLINE=1 让本地数据集不联网（0.4.4 已能纯本地加载，0.3.2 还会去查 hub refs）。
- ⚠️ **阻塞：数据集视频损坏**。烟雾测试报 `av.error.InvalidDataError: moov atom not found` @ `videos/observation.images.top/chunk-000/file-004.mp4`(312MB)。ffprobe 确认该文件坏(缺 moov=编码没 finalize)，meta 统计 **23 条 episode 里 20 条的俯视视频在这个坏文件里**(file_index=4→20条)，仅 3 条好(file 0/1/2)；腕部视频全好。**最可能：打包 `block_in_box.7z` 时 Insta360 俯视大视频还没编码完**(对应采集时的"编码冻结"现象)，7z 把未 finalize 的文件打进去了(7z 内记 327MB=解出 312MB，大小一致→源头就缺 moov)。
- ⏳ **下一步（待 Linux 端）**：在 Linux 机 `ffprobe ~/.cache/huggingface/lerobot/fanhao375/block_in_box/videos/observation.images.top/chunk-000/file-004.mp4`——好则**重打包重传**(数据没丢)；也坏则那 20 条俯视在采集时就没存好，需**重采**。环境这边已 ready，数据修好直接开训。

### 数据集 AV1 救援（Linux 端响应训练机阻塞）→ 重建全 h264 23 条
响应训练机报的 `top/file-004.mp4` moov 损坏。Linux 端 ffprobe 缺失(误判全坏)→ 改 **pyav 验证**:**源头完好**(file-004 帧数 7826/moov 在/全解码)，训练机"缺 moov"=**.7z 把 311MB 大文件传/打包时截断**(非采集丢)。另查出删条工具 `lerobot-edit-dataset` 默认把重编码文件转成了 **AV1**(libsvtav1)、训练机 AV1 解码也有隐患(本机 cv2 也解不动，pyav/libdav1d 才行)。
- **根治**：monkeypatch `dataset_tools._copy_and_reindex_videos` 强制 `vcodec="h264"`，从原始备份 `block_in_box_old`(28 条全 h264) 删 [0,4,17,26,27] → 新建 `block_in_box_h264`(**23 条全 h264、全部 pyav 验证可解码**，10125 帧)。
- 打包 `~/block_in_box_h264.tar.gz`(400MB)，校验归档完整(file-004 归档内字节=磁盘一致无截断)，MD5 `4b43f95d2b3d61c6fe0246542a28c9c0` 供训练机核对。**教训:传输/打包必校 MD5、别用 7z 边编码边打包**。原始 `block_in_box_old` 留作终极底本。
- ⏳ 训练机:核对 MD5 → 解压到 `~/.cache/huggingface/lerobot/fanhao375/block_in_box_h264` → `lerobot-train --dataset.repo_id=fanhao375/block_in_box_h264 ... --dataset.video_backend=pyav`。

### 上游同步:主仓 README 加可选硬件清单（仅此 1 条，其余 4 仓 0 落后）
例行检查 5 仓 upstream。**仅主仓 1 条纯文档新提交**已同步；MotorBridge/ROS2/StarArm_102/control_py(DM 线 develop-dm) 全 0 落后。
- **主仓 `654ebdc add:optional hardware`**：5 个多语言 README +409 行「推荐可选硬件」章节(相机 Gemini 2/336/335LG、RealSense D435i/D405、GMSL2 单目 + 夹爪/StarArm，正好列了我们在用的 Gemini 2)。纯文本无大文件、引用图仓内已存。**只取 `67d233c..654ebdc` README delta 打补丁(单亲)**,规避全树 squash 把 powerstep 大图拽回的老坑。
- **control_py develop +17 / main +26 不追**：develop-dm 0 落后(DM 线最新);develop 是 RS 线 + EN + 06-24 评估过的破坏性 API 重构,维持 `0163c08`。
- 打 `baseline-2026-06-27`,push origin/main + tag。详见 [`上游更新记录/2026-06-27_同步详情.md`](./上游更新记录/2026-06-27_同步详情.md)。

---

## 2026-06-28

### 第二批采集:block_in_box_v2 共 13 条全 h264 干净数据
接训练数据扩充。Insta360 曾掉线(USB 没插好,`lsusb` 无 2e1a)→ 重插回 video6。rerun 实时预览确认双路 OK 后开采。
- **新坑①(已踩):0 帧 episode 直接崩进程** —— 一进录制还没动就按 `→`(0 帧)→ `validate_episode_buffer: You must add one or several frames` 抛错、**整个 lerobot-record 挂掉**。**务必先动 102 采到帧再按 →**。崩前 ep0(604帧)已存,`--resume=true` 续录接着采。
- **采集**:`block_in_box_v2`(全 h264 配置 + Claude 盯日志喊🟢录/🔴停节奏),录 13 条 ep0~12 → 验收 **13 条全有效**(主臂 100-110°/从臂 180-205°,0 废条)、视频全 h264。打包 `~/block_in_box_v2.tar.gz`(192MB,MD5 `e86b31730b31948a9db01a5e993de979`)。
- **新坑②:merge 合并失败** —— `lerobot-edit-dataset merge`(底层 `aggregate_datasets`)拼接 h264 视频时 muxer 报 `non monotonically increasing dts`(已知拼接 bug)。**放弃合并,两份分开交付**:`block_in_box_h264`(23 条,MD5 `4b43f95d…`)+ `block_in_box_v2`(13 条),合计 **36 条**,训练机训哪个都行(建议先训 23 条那份验证流程)。
- 数据集仍都在 `~/.cache`、`.gitignore` 已忽略 `block_in_box*`,不入仓。

### ⭐⭐ 首个 ACT 模型训练跑通：50000 步收敛，loss 6.8 → 0.063

承接 06-27 的数据损坏阻塞 + AV1 救援。Linux 端重导出的全 h264 数据传到训练机后，**整条复刻链路第一次完整闭环：采集 → 训练 → 出模型**。

- **数据修复落地**：把 Linux 传来的 `F:\...\block_in_box_h264.tar.gz`(全 8 路视频 ffprobe 全好)解包，**直接覆盖替换**训练机缓存里那份坏的 `~/.cache/huggingface/lerobot/fanhao375/block_in_box`(没另起 `block_in_box_h264` 的 repo_id，原地换数据)。替换后 8 个视频 ffprobe 全部可解码，之前坏的 `top/file-004.mp4` 也好了。
- **烟雾测试(20 步)通过**：loss 57→10.7、grad_norm 875→235、checkpoint 正常落盘、无 OOM、稳态 ~2.4 step/s。确认环境+数据都 OK 才开全量。
- **全量训练参数**：`--policy.type=act --dataset.video_backend=pyav --batch_size=8 --steps=50000 --save_freq=10000 --num_workers=4 --wandb.enable=false`，`HF_HUB_OFFLINE=1`。ACT 模型 **52M 参数**，5060 Ti 占显存 ~11.3/16G、GPU 99%、~2.4 step/s。
- **loss 收敛**：step 200→6.825 / 1K→1.887 / 10K→~0.30 / 20K→~0.11 / **50K→0.063**(grad_norm 7.4)，平滑下降无发散。`End of training` 21:15:06 正常收尾。产出 5 个 checkpoint `010000`~`050000` + `last`。

### ⭐ 断点续训实测可用（中途电脑睡眠中断 → 无损接回）

- **中断原因**：训练用 `nohup setsid` **完全脱离会话**(关 Claude/终端都不影响)，但跑到 ~27K 步时**电脑睡眠**→ WSL2 随宿主挂起→进程停。⚠️**教训：训练期间务必把 Windows 电源「睡眠」设为「从不」**，只有睡眠/休眠或 `wsl --shutdown` 能中断它。
- **无损续训**：最近存档点是 2 万步(`save_freq=10000`→只能从万步整点续，20K→27K 那 7 千步重跑)。续训命令一行：
  ```
  lerobot-train --config_path=<output_dir>/checkpoints/last/pretrained_model/train_config.json --resume=true
  ```
  自动加载权重+优化器+RNG 状态，从 20K 接着跑(loss 0.114 与断点前连续，证明是续训非重启)。`train_config.json` 已含 `video_backend=pyav` 等全部原参数，无需重传。

### 部署包已就位（待拷回 Linux 推理）

- **关键区分**：每个 checkpoint 目录 **591M**(含 `training_state/` 优化器状态，**仅续训用**)；**部署只需 `checkpoints/0XXXXX/pretrained_model/` 子目录(~200M)** = `model.safetensors`(197M 权重) + `config.json` + `train_config.json` + 归一化 `policy_pre/postprocessor*`。
- 已打包 **`F:\chengshenzhilu\Robot\reBot-DevArm\block_in_box_act_50k.tar.gz`(183M)**(`.gitignore` 的 `*.tar.gz` 已排除，不入仓)，解包得 `pretrained_model/`。
- ⏳ **下一步(Linux 端部署)**：拷过去解包 → 在原 `lerobot-record` 采集配置上加 `--policy.path=<解包路径>/pretrained_model` → 机械臂从遥操作转为**自主积木入盒抓取**。相机/机器人配置须与训练一致(top 俯视+wrist 腕部双目、7 维 action/state)。先空盒试几次看成功率；不理想可换 30K/40K checkpoint 对比，或补采数据重训。
- 注：训练产物都在 WSL `~/outputs/train/block_in_box_act/`，**不入仓**(大文件)，本仓只记流程。

### 上游检查：仅 StarArm_102 docs 同步，control_py 维持 hold（理由纠正）
例行检查 5 仓 upstream。⭐ 检查前按规则 **spawn 独立 subagent 逐仓复核**，纠正了初判的 3 个理由错误。详见 [`上游更新记录/2026-06-28_同步详情.md`](./上游更新记录/2026-06-28_同步详情.md)。
- **主仓 / MotorBridge(v0.4.8) / ROS2：0 落后**（主仓 `654ebdc` 已 blob 级落地；MotorBridge feature 分支全已并；ROS2 new-dev 已并）。
- ✅ **StarArm_102 同步 `e61f34e→d2eb059`**：2 条纯文档无代码（README 结构重排 + `Python_SDK/README.md→PYTHON_SDK_GUIDE.md` 改名并补 **HD 锁定按键板**用法、代码我方早有 + 新增 2.6MB 图）。submodule 内图随 pin 带过来、无需 gitignore（仓本就跟踪 6MB JPG）。fork ff 已 push，回滚点 `e61f34e`。
- **control_py 维持 hold**：上游删 `develop-dm/rs/copy` 合并回 develop+main、新增 Windows 化 `win` 分支，但破坏性重构 `RobotArm→RebotArm`+JointGroup 在 develop/main/win 都在（`HEAD..upstream/develop`=121 文件 +3496/-4005）；我们遥操作走 LeRobot 插件不依赖其高层 API，整体合入=未验证架构迁移、收益≈0。⚠️ **subagent 纠正**：① 我们的 `idx_q` 限位修复 **upstream 至今没有**（它仍按 jid 索引=未修 IK bug，关节1-5限位错/joint6 IndexError）=**我方必保的唯一硬修复**，将来迁移须手工移植，别误以为上游已有而丢弃；② pyc 重跟踪仅 develop（main 干净）；③ 漏判的 `win` 分支也建在重构上，登记备案。
- 本次对 control_py 唯一改动（纯本机维护非同步）：清残留 `actuator/__pycache__/gripper.cpython-310.pyc`，fork develop `0163c08→be65b46`，hold 基线本质不变。
- **策略**：control_py **无限期 hold ≠ 永不维护**。触发重评条件：① 要用某个仅重构后才有的功能；② 有真机时间做完整迁移+回归测试（重力补偿/IK/DM 全验）。

### ⭐⭐ 真机部署首跑:ACT 模型自主驱动 601(复刻全链路闭环)
把训练机的 `block_in_box_act_50k.tar.gz`(183M,完整 `pretrained_model/`)拷回本机 `/home/pc/robot/reBot-DevArm/`(已被 gitignore),解压到 `~/act_models/pretrained_model`。模型输入特征 `observation.state` + `observation.images.{top,wrist}`,与采集相机一致。
- **部署=官方标准流程**:`lerobot-record` 把 `--teleop` 换成 `--policy.path=~/act_models/pretrained_model`(无遥操作,模型自己出动作)。整套**采集→训练→部署**与 LeRobot/Seeed 官方模仿学习三步法 100% 一致,本地只加硬件适配(达妙/相机MJPG/h264),不改算法。
- **首跑结果**:① 第一次失败 `ensure_mode failed: register 10 write ack not received within 50ms`=**从臂电机供电没开**(达妙桥 USB 亮但电机要单独供电),开电源后正常连接。② Insta360 当天掉线 2 次(USB 接触不良,重插恢复)。③ 连上后模型自主运行:**601 会自己动、动作大致对、能抓到积木** —— 但**夹爪抓住后不松开**(紧夹不放)。
- **"夹完不放"根因分析(数据/模仿学习层面,非部署bug)**:训练仅 23 条偏少;"松开"只在每条末尾零点几秒=正样本极少、被"夹住"的多数帧淹没;夹爪开合数值幅度远小于大臂关节 100-200°→loss 被关节主导、夹爪通道被忽视;长程任务末端误差累积,到不了演示里"松开时"的精确画面=分布外。**改进**:下次采集刻意强化"放开"(到盒上方停顿明显张爪)、采到 50+ 条、松开时机一致、可补纯"放置+松开"片段。
- **里程碑**:**复刻链路首次真机闭环**——采集→训练→出模型→真机自主执行已全程跑通,任务完成度约一半(抓✅ 放❌)。停止用 `pkill -INT`(优雅断开→`disable_torque_on_disconnect` 关扭矩→夹爪松开放掉积木,臂变软需扶)。部署回放数据 `eval_block_in_box` 无用可删。

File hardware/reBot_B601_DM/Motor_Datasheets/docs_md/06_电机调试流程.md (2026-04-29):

# 06 电机调试流程

> DM-J4310-2EC V1.2 调试与校准

本章节涵盖电机的完整调试流程，包括编码器校准、参数标定、串口读写参数等操作。

---

## 调试前准备

### 软件要求
- 使用 **V2.0.0.0 及以上版本**的上位机调试助手
- 推荐版本：V2.0.3.4

### 硬件连接
1. 连接电机的**串口**（用于参数配置和校准）
2. 连接电机的**CAN口**（用于运动控制调试）
3. 连接**电源接口**

### 连接步骤
1. 打开调试助手软件
2. 选择相应的串口设备并打开串口
3. 给电机供电
4. 串口会打印信息，显示当前的 **Control Mode**（驱动模式）

> **注意**：不同模式采用不同的命令格式，参考 CAN 通信章节

---

## 电机侧编码器校准

### 校准目的
修正传感器的安装误差，消除电机转子位置检测偏差。

### 何时需要校准
- **电机出厂已校准**，正常情况下无需重新校准
- 以下情况需要重新校准：
  - 更换驱动板
  - 电机出现异常震动
  - 其他非正常状态

### 校准前准备
- 保证电机可以**自由转动**
- 最好电机能够**空载运行**
- 校准过程中电机会正向反向转动一个转子周期

### 校准步骤

#### 步骤1：启动校准
点击"校准"按钮，电机会开始转动。

#### 步骤2：自动参数识别
- 电机会自动进行参数识别
- 过程中电机会有旋转运动，**请注意固定好电机**
- 识别完成后，电机会自动进行传感器校准

#### 步骤3：查看传感器波形图
校准完成后会显示传感器波形图：

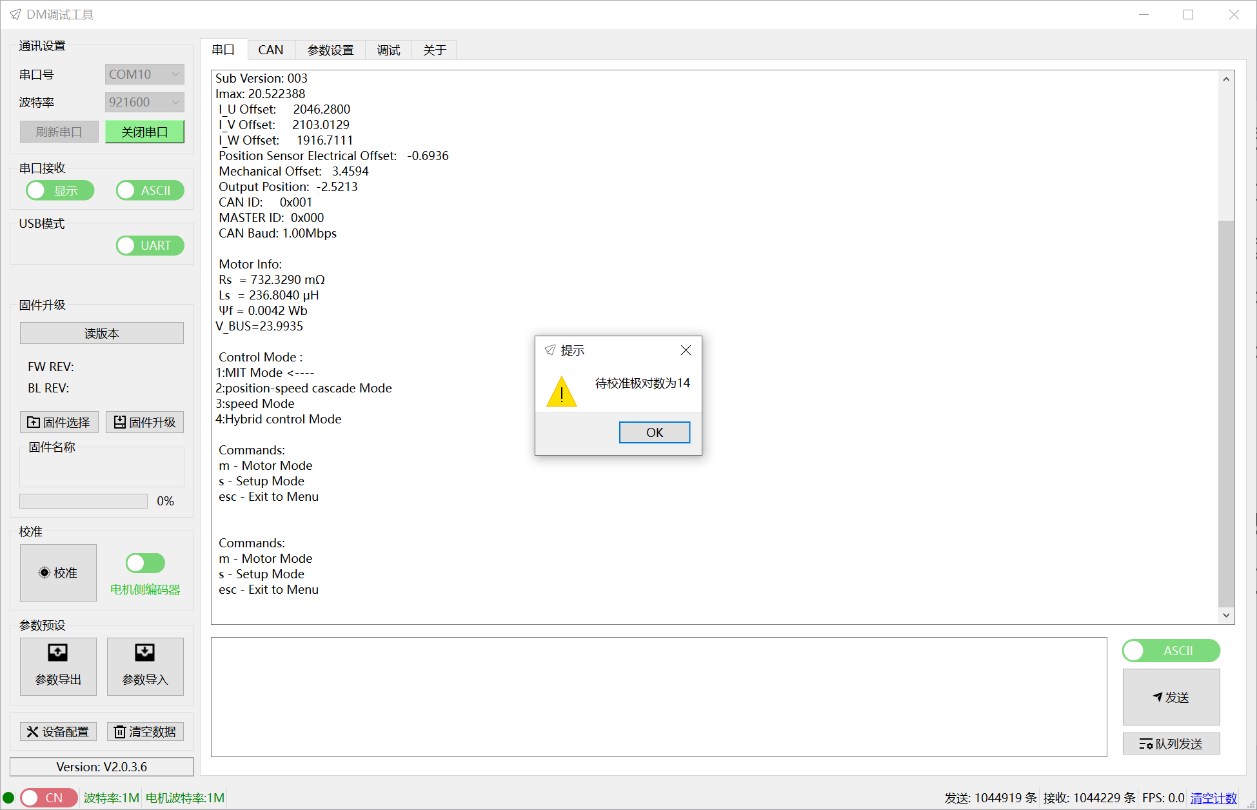
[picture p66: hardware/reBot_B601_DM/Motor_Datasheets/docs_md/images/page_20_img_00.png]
传感器波形图


- **红色曲线**：实际补偿值
- **蓝色曲线**：理想范围

> **注意**：红色曲线的最大值不要明显超过蓝色曲线，否则校准失败，需重新校准。

#### 步骤4：校准数据上传
校准完成后，会自动上传校准值：

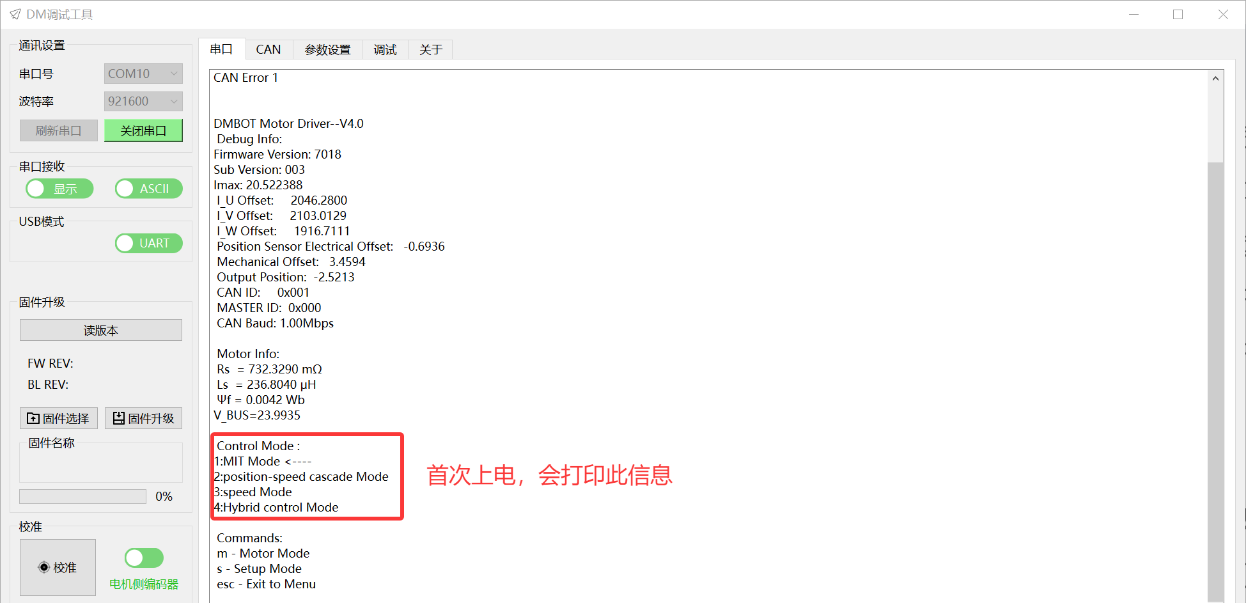
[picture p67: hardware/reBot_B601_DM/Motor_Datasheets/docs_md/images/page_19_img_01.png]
校准数据上传


包括：
- 极对数
- 补偿数据（Compensation Data）

#### 步骤5：校准数据排查
**特别关注"Compensation Data 补偿"的值**：
- 建议不要超过 **±300**
- 若超过 300，可能原因：
  1. **极对数识别错误**
  2. **电机阻力过大**，导致卡顿
  3. **传感器安装不规范**

---

## 参数标定

### 标定目的
识别电机的相电阻、相电感、磁链等重要参数。

### 何时需要标定
- **电机出厂已标定**，正常情况下无需重新标定
- **电机校准过后也已完成标定**
- 更换驱动板后需要重新标定

### 标定步骤

#### 步骤1：启动标定
1. 点击"参数设置"标签卡
2. 点击"参数标定"按钮
3. 驱动器进入辨识步骤

#### 步骤2：保持空载
- 期间电机会转动
- 应保持**空载状态**
- 固定好电机

#### 步骤3：查看辨识结果
辨识完成后，会自动上传辨识的结果：

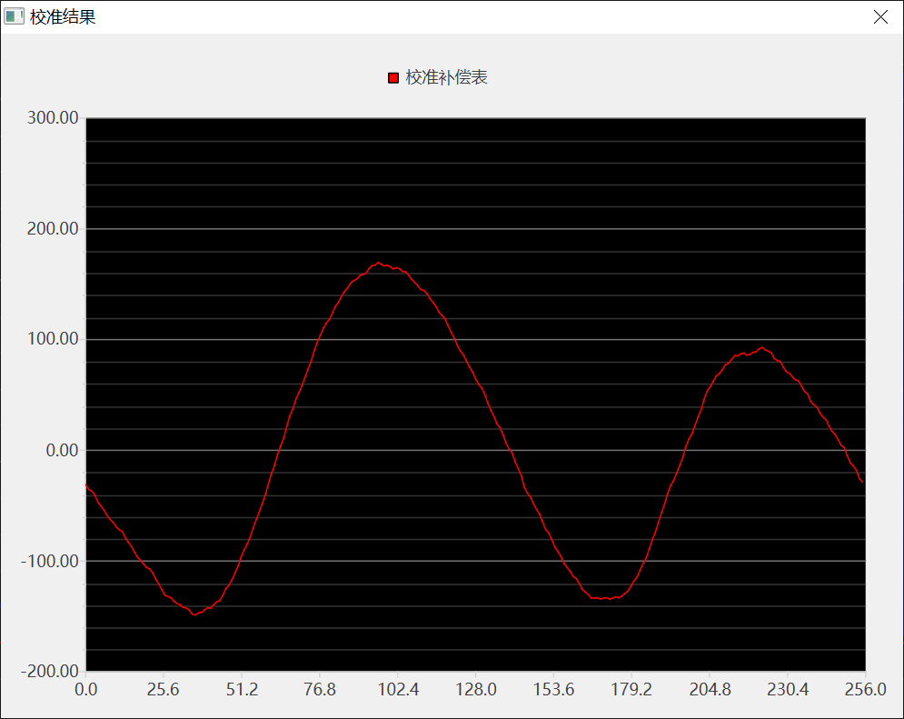
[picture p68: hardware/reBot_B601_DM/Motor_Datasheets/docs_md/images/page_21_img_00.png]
参数标定结果


- 相电阻
- 相电感
- 磁链
- 粘滞系数（仅作为参考，可多次标定）

> **注意**：除粘滞系数外，其他参数**不能出现负值**。若出现负值，请确认电机状态后再行标定。

---

## 输出轴编码器校准

### 适用范围
**仅双编码器电机需要**进行输出轴编码器校准。

### 校准目的
提升输出轴编码器准确度。

### 何时需要校准
- **电机出厂已校准**，正常情况下无需重新校准
- 以下情况需要重新校准：
  - 更换驱动板
  - 输出位置变化等非正常状态

### 校准前准备
- 保证电机可以**自由转动**
- 确保电机**空载运行**
- 校准过程中电机会正向转动一周

### 校准步骤

#### 步骤1：切换到输出轴编码器模式
点击校准按钮旁边的滑块，切换至显示"**输出轴编码器**"状态。

#### 步骤2：启动校准
点击"校准"按钮，电机开始旋转一周。

#### 步骤3：查看原始数据波形
上传编码器原始数据波形：

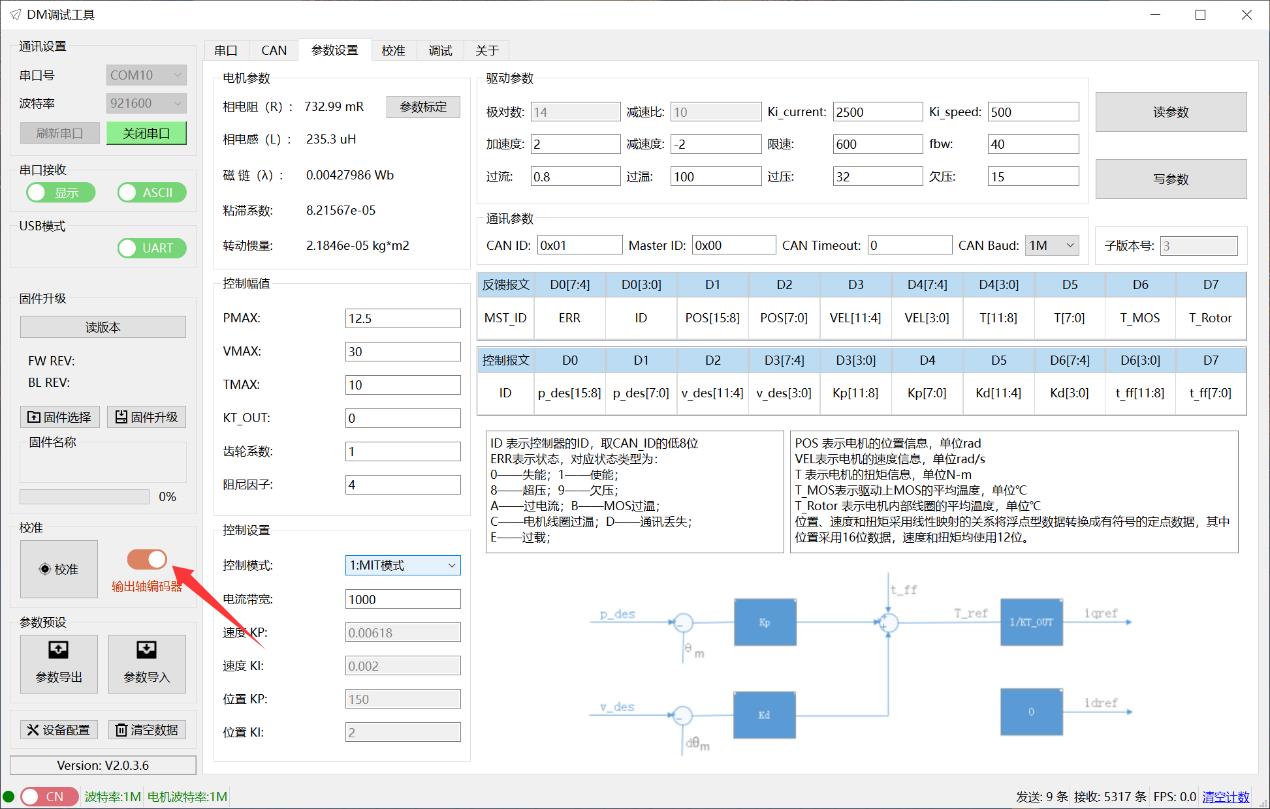
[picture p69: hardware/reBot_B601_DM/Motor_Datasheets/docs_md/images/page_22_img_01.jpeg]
输出轴编码器波形


#### 步骤4：查看校准值
校准完成后，会自动上传显示校准值：

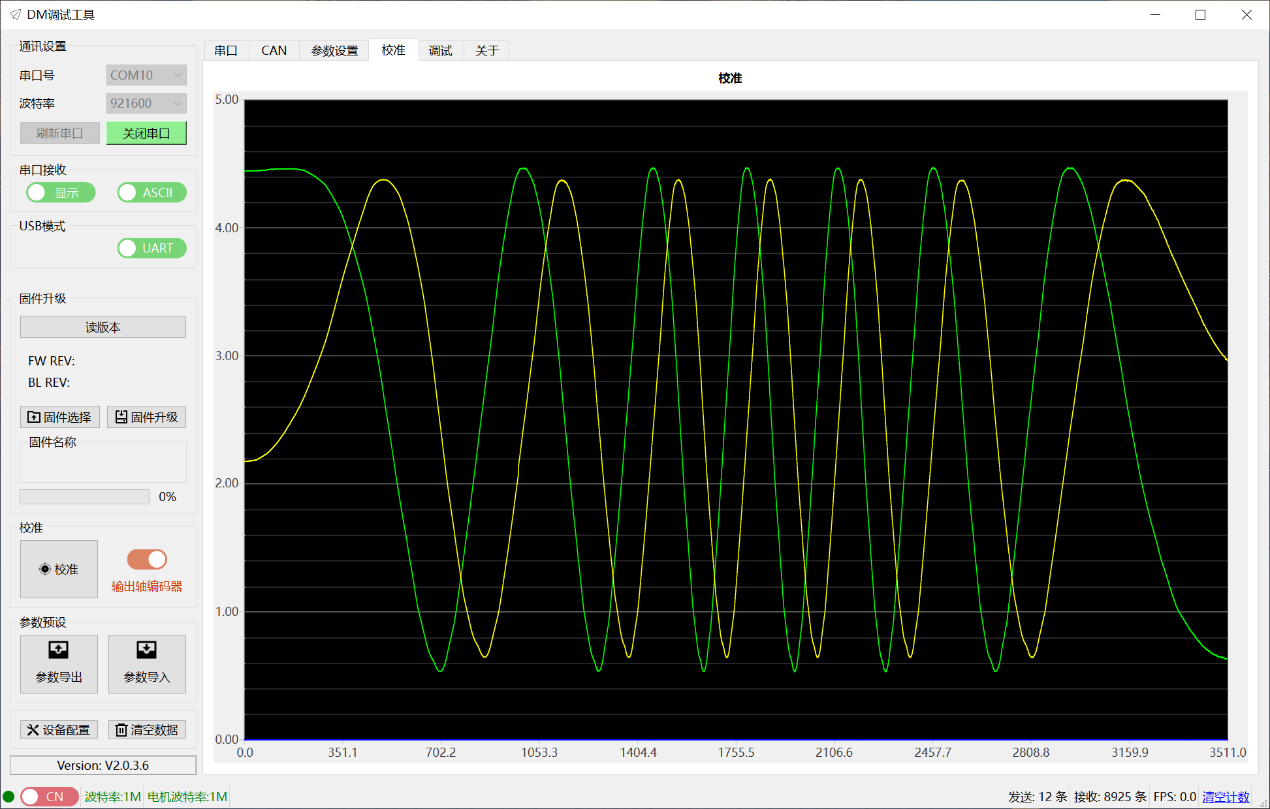
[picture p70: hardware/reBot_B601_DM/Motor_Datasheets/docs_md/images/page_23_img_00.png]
输出轴校准值


#### 步骤5：数据校验
- 驱动器会自动进行数据校验
- 如校验数据偏差过大，会报错：
  - **错误类型**：3
  - **红灯闪烁**
- 一般情况下出错是由于**输出轴编码器异常**导致，可联系售后解决

---

## 串口读写参数

### 1. 读参数

#### 操作步骤
1. 在"参数设置"标签卡下
2. 点击"读参数"按钮
3. 驱动器会将存储的参数上传到调试助手

> **注意**：点击读参数成功后，会同步更新调试界面的参数（如 PMAX、ID 等）

#### 读取到的参数包括

##### (1) 驱动参数

| 参数名称 | 说明 | 注意事项 |
|---|---|---|
| **极对数** | 电机的极对数 | 通过校准自动得出，**切勿修改** |
| **欠压** | 电源电压下限 | 低于此值驱动器无法控制电机，默认 20V |
| **过压** | 电源电压上限 | 超过此值驱动器报错并退出使能 |
| **加速度/减速度** | 加减速限制 | 非 MIT 模式使用，单位 Krad/s² |
| **减速比** | 电机减速比 | 影响输出转速和位置，**切勿修改** |
| **过温** | 线圈温度保护值 | 建议不超过 100℃ |
| **CAN_ID** | 驱动器 ID 号 | 16进制，建议设置小于 16 |
| **Master ID** | 反馈信息帧 ID | 16进制 |
| **CAN Timeout** | CAN 通讯超时时间 | 32位整数，单位 50us |
| **限速** | 最大运行速度 | 仅速度模式使用，单位 rad/s |
| **过流** | 最大相电流限制 | 百分比数 |
| **CAN波特率** | CAN 通讯速率 | 支持 125Kbps - 5Mbps |
| **Ki_current** | 电流环增强系数 | 不建议修改 |
| **fbw** | 速度环滤波带宽 | 单位 Hz |
| **Ki_speed** | 速度环增强系数 | 建议范围 200-800 |
| **子版本号** | 固件子版本号 | 只读 |

##### (2) 电机参数
此部分参数由驱动器自动辨识得出（更换驱动板需要标定一次）。

##### (3) 控制幅值

| 参数名称 | 说明 |
|---|---|
| **PMAX** | MIT 模式：命令映射值；其他模式：反馈映射值 |
| **VMAX** | 同 PMAX |
| **TMAX** | 同 PMAX |
| **KT_OUT** | 电机扭矩系数，参数辨识准确时设为 0 |
| **齿轮系数** | 齿轮力矩传动系数，≤ 1.0 |
| **阻尼因子** | 电流环与速度环控制带宽比 |

##### (4) 控制设置

| 参数名称 | 可选值 |
|---|---|
| **控制模式** | MIT 模式、位置速度模式、速度模式、力位混控模式 |
| **电流带宽** | 电流环增益系数，默认 1000 |
| **速度 KP/KI** | 速度环参数 |
| **位置 KP/KI** | 位置环参数 |

### 2. 写参数

#### 操作步骤
1. 核对驱动参数、控制幅值、控制设置等参数
2. 对需要修改的参数进行修改
3. 点击"写参数"保存至驱动器

#### 重要注意事项
1. **请勿修改极对数和减速比参数**
2. 点击"写参数"后，驱动器将**自动软件重启**，无需外部重启电源
3. 点击"写参数"时请确保电机处于**"失能"状态**，以防止安全事故
4. "暂存"按钮只针对控制器参数生效，且**掉电后会丢失**

---

## 调试模式

### 调试前准备
- 此功能**仅在连接 CAN 接口**的情况下可操作
- 只可以调试单个电机
- 操作前需连接 CAN 线至驱动器板
- 调试前需确认接线线序以及当前控制模式

### 控制模式的选择与确认

#### 设置控制模式
1. 点击调试助手"参数设置"
2. 在控制设置中点击"控制模式"
3. 可选择以下四种模式：
   - MIT 模式
   - 速度位置模式
   - 速度模式
   - 力位混控模式
4. 点击"写参数"进行控制模式设置
5. 弹出提示窗口："写参数成功！"
6. 因"写参数"功能会自动复位，无需再重新给驱动器上电

#### 确认当前控制模式
方法1：根据上电串口打印数据判断，箭头指向的模式即为当前驱动的控制模式  
方法2：在参数设定页面重新读参数后显示的信息

---

## MIT 模式调试

### 模式确认
1. 参考"控制模式的选择与确认"，选择当前为 MIT 模式
2. 在调试页面中选择对应的"MIT"子标签卡
3. 确保 CAN ID 正确

### MIT 模式的三种控制方法

#### 1. 速度控制

**步骤1：使能电机**
- 电机模式栏点击"使能"按钮
- 驱动器绿色灯亮起，表示电机已使能

**步骤2：给定速度**
- 例如：速度给定 5 rad/s
- KD 给 1 N·s/r
- 其余全部给 0
- 勾选"定时发送"框
- 依次点击"更新"按钮和"发送"按钮
- 可在调试界面查看参数曲线变化图
- **注意固定电机**

**步骤3：退出调试**
- 依次点击"停止"和"失能"按钮
- 驱动器红色灯亮起，表示退出电机模式

#### 2. 位置控制

**步骤1：使能电机**
- 电机模式栏点击"使能"按钮
- 驱动器绿色灯亮起

**步骤2：给定位置**
- 注意电机初始位置
- 给定"位置"参数时，避免与初始位置差距过大，引起电机冲击

#### 3. 力矩控制
（参考速度控制和位置控制的操作流程）

### 调试参数修改
- 根据调试需求修改控制参数
- 在原界面直接对参数进行修改
- 保持勾选"定时发送"
- 点击"更新"按钮即可进行调试

### 实时监控
调试助手界面实时显示：
- 电机温度
- 驱动温度
- 电机运行状态
- 也可通过反馈帧查看（参考"4.1 反馈帧"章节）

---

## 位置速度模式调试

### 模式设置
1. 在参数页面将电机模式切换成**位置速度模式**
2. 点击"写参数"后生效
3. 在调试页面中选择对应的"位置"子标签卡

### 调试步骤

**步骤1：确认 CAN ID**
- 可通过串口打印信息获取
- 或者参数设置页面获取
- 也可以通过调试页面读取、设定按钮设定

**步骤2：使能电机**
- 电机模式栏点击"使能"按钮
- 驱动器绿色灯亮起，表示电机已使能

**步骤3：设定参数**
- 设置参数前，需注意电机的初始位置
- 以此为参考对参数进行设置
- 电机按照设定速度运转到指定位置

---

## 速度模式调试

（操作流程类似位置速度模式，在参数页面切换成速度模式即可）

---

## 力位混控模式调试

### 模式设置
1. 在参数页面将电机模式切换成**PVT 模式**
2. 点击"写参数"后生效
3. 在调试页面中选择对应的"位置"子标签卡

### 调试步骤

**步骤1：确认 CAN ID**
- 可通过串口打印信息或参数设置页面获取
- 也可以通过调试页面读取、设定按钮设定

**步骤2：使能电机**
- 电机模式栏点击"使能"按钮
- 驱动器绿色灯亮起，表示电机已使能

**步骤3：设定参数**
- 设置参数前，需注意电机的初始位置
- 以此为参考对参数进行设置
- 例如：
  - 位置：10 rad
  - 速度：5 rad/s
  - 电流：20%
- 勾选"定时发送"框

---

## 常见问题排查

### 1. 电机侧编码器校准失败
- 检查极对数识别是否正确
- 检查电机阻力是否过大
- 检查传感器安装是否规范
- Compensation Data 补偿值是否超过 ±300

### 2. 参数标定出现负值
- 确认电机状态
- 重新进行标定

### 3. 输出轴编码器校准报错（错误类型3）
- 红灯闪烁
- 一般是输出轴编码器异常
- 联系售后解决

### 4. 写参数后电机异常
- 确认是否在失能状态下写参数
- 检查是否误修改了极对数或减速比
- 检查 CAN ID 是否冲突

---

## 安全注意事项

1. **校准和标定时**：
   - 确保电机空载运行
   - 固定好电机，防止意外转动
   - 保证电机可以自由转动

2. **写参数时**：
   - 必须在失能状态下操作
   - 不要修改极对数和减速比

3. **调试时**：
   - 注意电机初始位置
   - 避免给定值与初始位置差距过大
   - 固定好电机，防止冲击

4. **温度监控**：
   - 实时关注电机温度和驱动温度
   - 过温保护值建议不超过 100℃

---

## 附录：寄存器地址表（部分）

| 地址 | 十进制 | 参数名称 | 读写 | 范围 | 类型 |
|---|---|---|---|---|---|
| 0x1A | 26 | KI_ASR (速度环Ki) | RW | [0.0, fmax] | float |
| 0x1B | 27 | KP_APR (位置环Kp) | RW | [0.0, fmax] | float |
| 0x1C | 28 | KI_APR (位置环Ki) | RW | [0.0, fmax] | float |
| 0x1D | 29 | OV_Value (过压保护值) | RW | TBD | float |
| 0x1E | 30 | GREF (齿轮力矩效率) | RW | (0.0, 1.0] | float |
| 0x1F | 31 | Deta (速度环阻尼系数) | RW | [1.0, 30.0] | float |
| 0x20 | 32 | V_BW (速度环滤波带宽) | RW | (0.0, 500.0) | float |
| 0x21 | 33 | IQ_c1 (电流环增强系数) | RW | [100.0, 1.0e4] | float |
| 0x22 | 34 | VL_c1 (速度环增强系数) | RW | (0.0, 1.0e4] | float |
| 0x23 | 35 | can_br (CAN波特率代码) | RW | [0, 4] | uint32 |
| 0x3B | 59 | Imax (驱动板最大电流) | RO | / | float |
| 0x3C | 60 | VBus (电源电压) | RO | / | float |
| 0x3D | 61 | Tpcb (驱动板温度) | RO | / | float |
| 0x3E | 62 | Tmtr (电机温度) | RO | / | float |
| 0x50 | 80 | p_m (电机当前位置) | RO | / | float |
| 0x51 | 81 | xout (输出轴位置) | RO | / | float |

> 注：  
> - RW：可读写  
> - RO：只读  
> - 电机输出轴位置：使用转子折算到输出轴的位置，单位 rad  
> - 输出轴位置：采用电机输出轴编码器计算得出的位置，单位 rad

---

**返回** [00_目录.md](00_目录.md)  
**上一章** [05_CAN通信.md](05_CAN通信.md)  
**下一章** [07_调试操作.md](07_调试操作.md)

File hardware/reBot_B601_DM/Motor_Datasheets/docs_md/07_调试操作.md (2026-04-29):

# 07 调试操作

> DM-J4310-2EC V1.2 各模式调试方法

本章节详细介绍各种工作模式下的调试操作步骤。

---

## 调试前准备

### 必要条件
- 此功能**仅在连接 CAN 接口**的情况下可操作
- 只可以调试单个电机
- 操作前需连接 CAN 线至驱动器板

### 确认事项
- 确认接线线序正确
- 确认当前控制模式
- 根据不同模式选择调试页面中的子标签卡

---

## MIT 模式调试

### 前置步骤

#### 1. 确认控制模式
参考"控制模式的选择与确认"，选择当前为 MIT 模式。

#### 2. 选择调试页面
在调试页面中选择对应的"MIT"子标签卡。

#### 3. 确认 CAN ID
可通过以下方式获取：
- 串口打印信息
- 参数设置页面
- 调试页面读取、设定按钮

---

### MIT 速度控制

#### 步骤 1：使能电机
- 电机模式栏点击"使能"按钮
- 驱动器**绿色灯亮起**，表示电机已使能

#### 步骤 2：给定速度

**参数设置示例**：

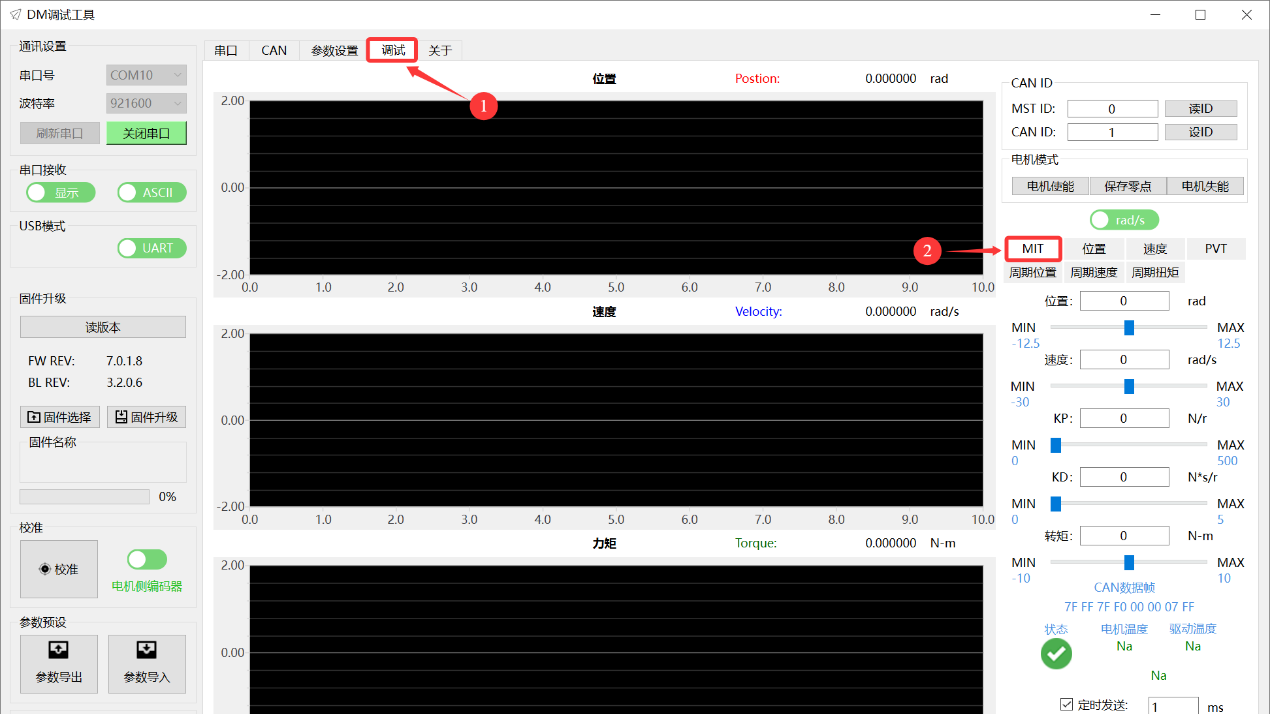
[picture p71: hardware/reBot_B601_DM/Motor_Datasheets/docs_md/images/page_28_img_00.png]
MIT速度控制界面


- 速度给定：5 rad/s
- KD：1 N·s/r
- 其余全部给 0
- 勾选"定时发送"框
- 依次点击"更新"按钮和"发送"按钮
- 可在调试界面查看参数曲线变化图

> **注意**：固定电机，防止意外转动

#### 步骤 3：退出调试
- 依次点击"停止"和"失能"按钮
- 驱动器**红色灯亮起**，表示退出电机模式

---

### MIT 位置控制

#### 步骤 1：使能电机
- 电机模式栏点击"使能"按钮
- 驱动器**绿色灯亮起**

#### 步骤 2：给定位置

**注意事项**：
- 注意电机初始位置
- 给定"位置"参数时，避免与初始位置差距过大，引起电机冲击

**保存零点**：
- 可通过控制命令栏点击"保存零点"
- 将电机当前位置设置为零点
- 方便"位置"参数设置

**参数设置示例**：

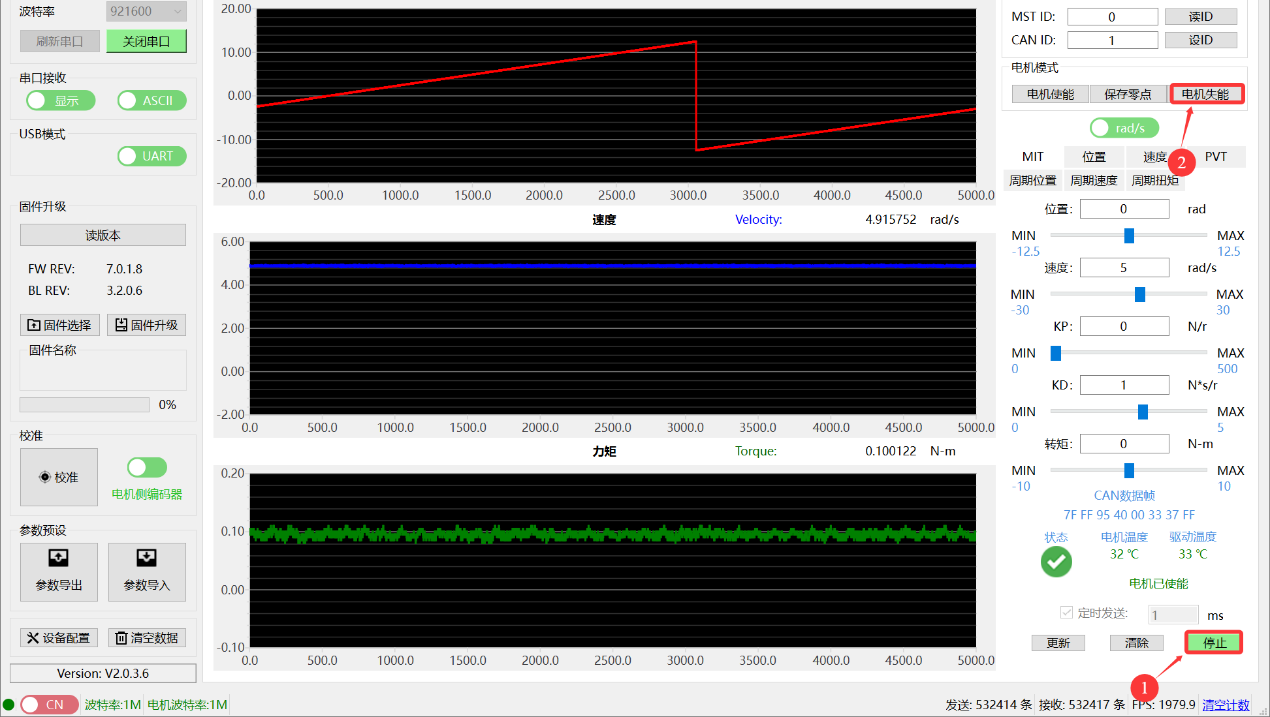
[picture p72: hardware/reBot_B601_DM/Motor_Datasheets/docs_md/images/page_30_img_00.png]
MIT位置控制界面


- 位置给定：3.14 rad
- KP：2 N/r
- KD：1 N·s/r
- 其余全部给 0
- 勾选"定时发送"框
- 依次点击"更新"按钮和"发送"按钮
- 可在调试界面查看参数曲线变化图

> **注意**：固定电机

#### 步骤 3：退出调试
- 先将电机停止下来
- 再依次点击"停止"和"失能"按钮
- 驱动器**红色灯亮起**

---

### MIT 力矩控制

#### 步骤 1：使能电机
- 电机模式栏点击"使能"按钮
- 驱动器**绿色灯亮起**

#### 步骤 2：给定力矩

> **警告**：空载情况下，即使给定很小的力矩，电机也会加速到最大转速旋转。

**参数设置示例**：

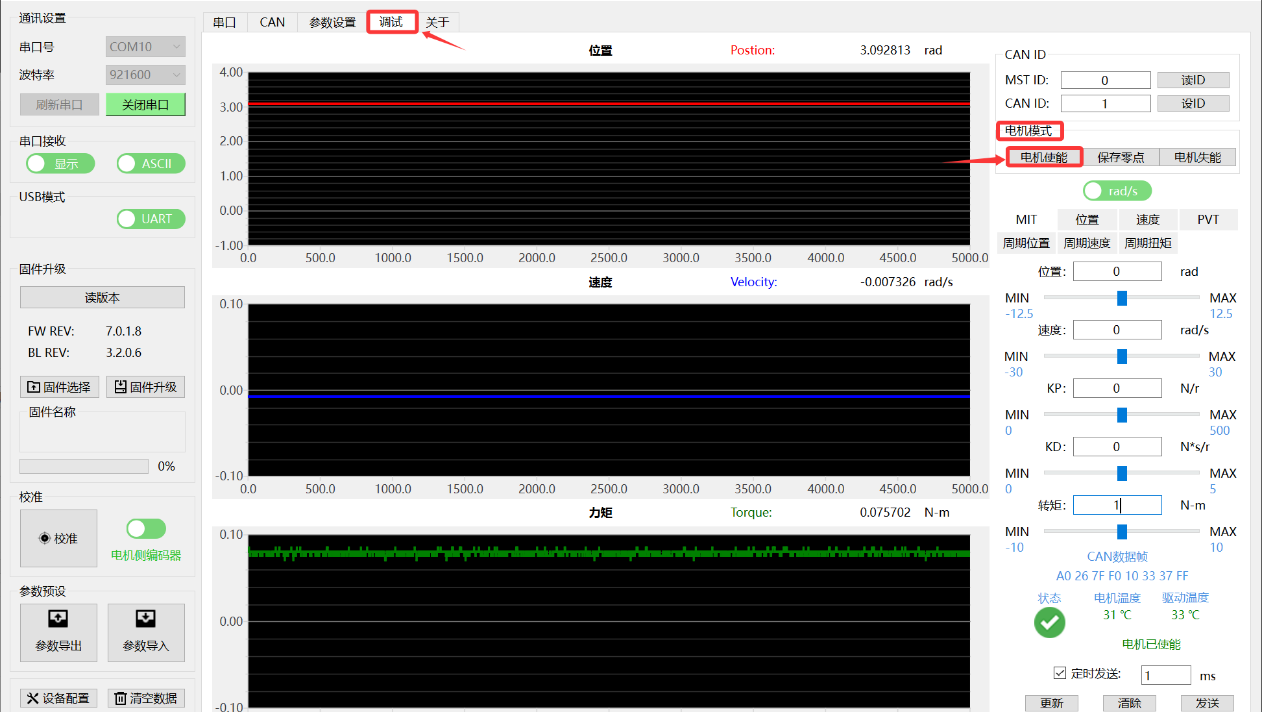
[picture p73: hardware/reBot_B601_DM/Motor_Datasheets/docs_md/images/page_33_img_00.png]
MIT力矩控制界面


- 转矩设定：1 N·m
- 其余全部给 0
- 勾选"定时发送"框
- 依次点击"更新"按钮和"发送"按钮
- 可在调试界面查看参数曲线变化图

> **注意**：固定电机

---

### MIT 调试参数修改

根据调试需求，需要修改控制参数查看调试变化：
1. 在原界面直接对参数进行修改
2. 保持勾选"定时发送"
3. 点击"更新"按钮即可进行调试

### 实时监控

调试助手界面实时显示：
- 当前电机温度
- 驱动温度
- 电机运行状态

也可通过反馈帧查看，反馈帧格式以及状态类型请查看"反馈帧"章节。

---

## 位置速度模式调试

### 前置步骤

#### 1. 切换控制模式
- 在参数页面将电机模式切换成**位置速度模式**
- 点击"写参数"后生效
- 在调试页面中选择对应的"位置"子标签卡

#### 2. 确认 CAN ID
可通过以下方式获取：
- 串口打印信息
- 参数设置页面
- 调试页面读取、设定按钮

---

### 调试步骤

#### 步骤 1：使能电机
- 电机模式栏点击"使能"按钮
- 驱动器**绿色灯亮起**，表示电机已使能

#### 步骤 2：设定参数

**注意事项**：
- 设置参数前，需注意电机的初始位置
- 以此为参考对参数进行设置
- 电机按照设定速度运转到指定位置

**参数设置示例**：

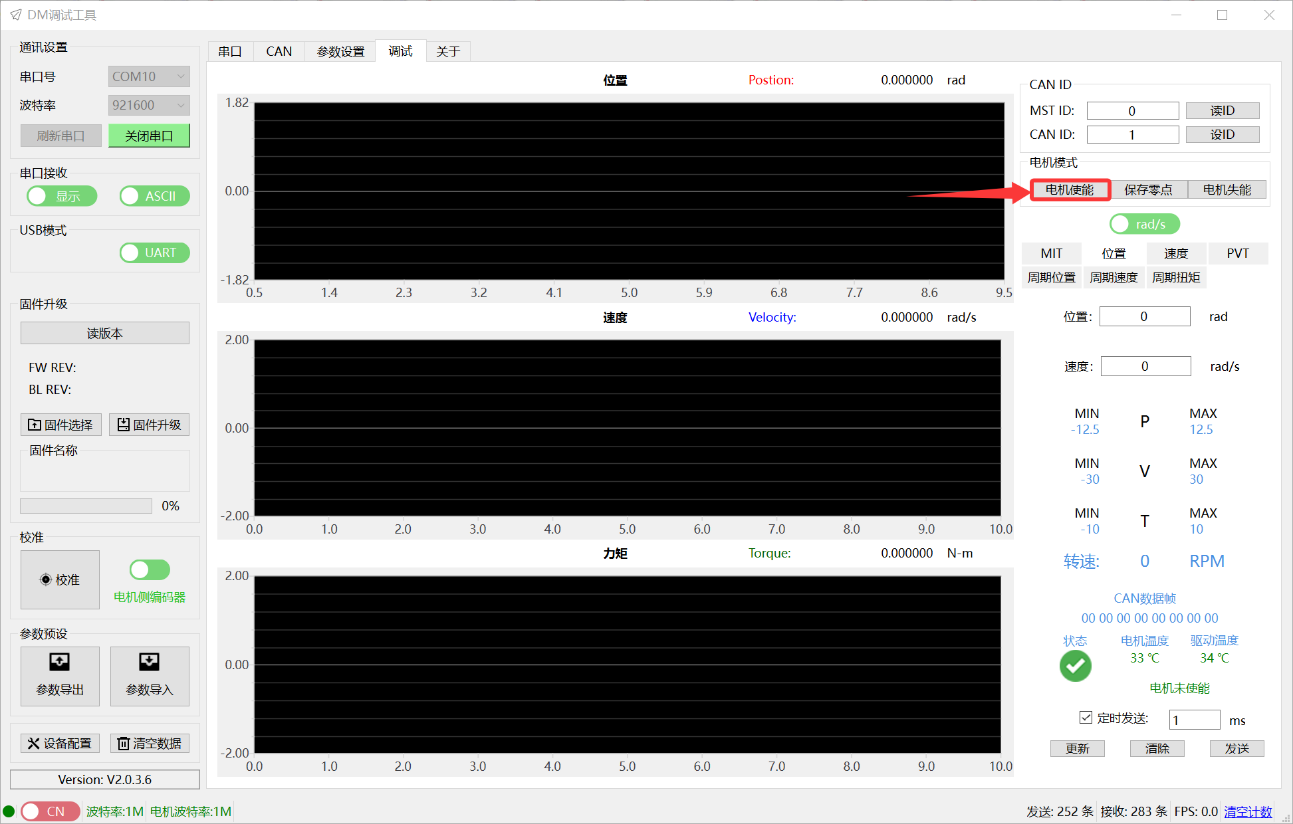
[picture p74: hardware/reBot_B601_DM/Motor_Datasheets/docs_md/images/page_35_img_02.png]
位置速度模式调试界面


- 位置：10 rad
- 速度：5 rad/s
- 勾选"定时发送"框
- 依次点击"更新"按钮和"发送"按钮
- 可在调试界面查看参数曲线变化图

> **注意**：固定电机

#### 步骤 3：调试参数修改

根据调试需求修改控制参数：
1. 在原界面直接对参数进行修改
2. 保持勾选"定时发送"
3. 点击"更新"按钮即可进行调试

#### 步骤 4：退出调试
- 依次点击"停止"和"失能"按钮
- 驱动器**红色灯亮起**

---

## 速度模式调试

### 前置步骤

#### 1. 切换控制模式
- 在参数页面将电机模式切换成**速度模式**
- 点击"写参数"后生效
- 在调试页面中选择对应的"速度"子标签卡

#### 2. 确认 CAN ID
可通过以下方式获取：
- 串口打印信息
- 参数设置页面
- 调试页面读取、设定按钮

---

### 调试步骤

#### 步骤 1：使能电机
- 电机模式栏点击"使能"按钮
- 驱动器**绿色灯亮起**

#### 步骤 2：设定速度

**参数设置示例**：

速度模式调试界面

- 速度：5 rad/s
- 勾选"定时发送"框
- 依次点击"更新"按钮和"发送"按钮
- 可在调试界面查看参数曲线变化图

> **注意**：固定电机

#### 步骤 3：调试参数修改

根据调试需求修改控制参数：
1. 在原界面直接对参数进行修改
2. 保持勾选"定时发送"
3. 点击"更新"按钮即可进行调试

#### 步骤 4：退出调试
- 依次点击"停止"和"失能"按钮
- 驱动器**红色灯亮起**

---

## 力位混控模式调试

### 前置步骤

#### 1. 切换控制模式
- 在参数页面将电机模式切换成**PVT 模式**
- 点击"写参数"后生效
- 在调试页面中选择对应的"位置"子标签卡

#### 2. 确认 CAN ID
可通过以下方式获取：
- 串口打印信息
- 参数设置页面
- 调试页面读取、设定按钮

---

### 调试步骤

#### 步骤 1：使能电机
- 电机模式栏点击"使能"按钮
- 驱动器**绿色灯亮起**

#### 步骤 2：设定参数

**注意事项**：
- 设置参数前，需注意电机的初始位置
- 以此为参考对参数进行设置

**参数设置示例**：

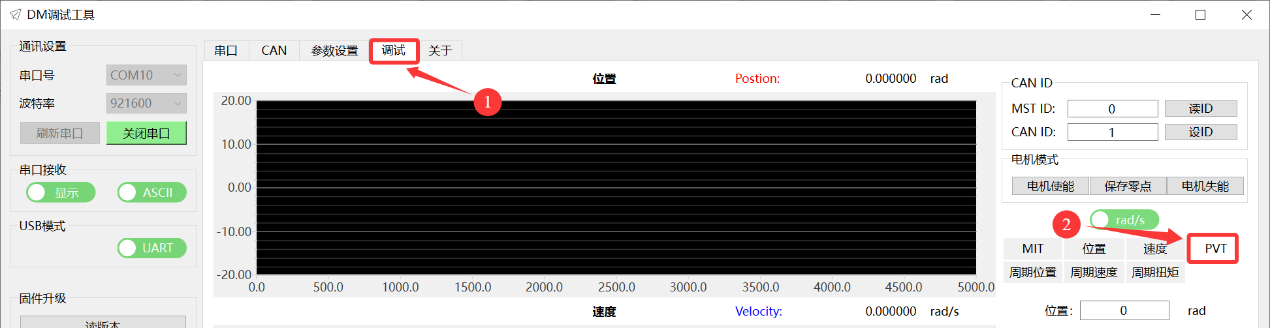
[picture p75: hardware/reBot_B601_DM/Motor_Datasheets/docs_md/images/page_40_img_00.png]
力位混控模式调试界面


- 位置：10 rad
- 速度：5 rad/s
- 电流：20%
- 勾选"定时发送"框
- 依次点击"更新"按钮和"发送"按钮
- 可在调试界面查看参数曲线变化图

> **注意**：固定电机

#### 步骤 3：调试参数修改

根据调试需求修改控制参数：
1. 在原界面直接对参数进行修改
2. 保持勾选"定时发送"
3. 点击"更新"按钮即可进行调试

#### 步骤 4：退出调试
- 依次点击"停止"和"失能"按钮
- 驱动器**红色灯亮起**

---

## 调试注意事项

### 安全事项
1. **固定电机**：调试时务必固定好电机，防止意外转动造成伤害
2. **初始位置**：给定位置参数时，注意与初始位置的差距，避免冲击
3. **空载力矩控制**：空载情况下，即使很小的力矩也会使电机加速到最大转速

### 操作规范
1. **定时发送**：修改参数后，保持勾选"定时发送"，点击"更新"按钮
2. **退出顺序**：先点击"停止"，再点击"失能"
3. **温度监控**：实时关注电机温度和驱动温度

### 参数调整
1. **小步调整**：参数调整时，建议小步调整，观察效果
2. **记录参数**：记录好的参数组合，方便后续使用
3. **保存参数**：调试完成后，记得保存参数到驱动器

---

## 调试技巧

### MIT 模式
- **速度控制**：适合测试电机基本运行状态
- **位置控制**：KD 不能为 0，否则会震荡
- **力矩控制**：空载时注意安全，建议带负载测试

### 位置速度模式
- 利用梯形加减速，实现平滑运动
- 调整加减速度参数，优化运动曲线
- 注意初始位置，避免大幅度跳变

### 速度模式
- 调整阻尼因子（2.0-10.0），优化速度响应
- 推荐阻尼因子：4.0
- 过小会震荡，过大响应慢

### 力位混控模式
- 电流限制可防止过大力矩
- 适合需要力控的应用场景
- 注意电流百分比设置

---

## 常见问题

### 1. 电机不响应
- 检查是否已使能（绿灯亮）
- 检查 CAN ID 是否正确
- 检查 CAN 线是否连接正常

### 2. 电机震荡
- MIT 位置控制：检查 KD 是否为 0
- 速度模式：调整阻尼因子
- 位置速度模式：调整 PID 参数

### 3. 电机冲击
- 检查初始位置与目标位置差距
- 降低速度给定值
- 增大加减速度时间

### 4. 温度过高
- 检查负载是否过大
- 检查电流限制是否合理
- 增加散热措施

---

**返回** [00_目录.md](00_目录.md)  
**上一章** [06_电机调试流程.md](06_电机调试流程.md)  
**下一章** [08_固件升级.md](08_固件升级.md)

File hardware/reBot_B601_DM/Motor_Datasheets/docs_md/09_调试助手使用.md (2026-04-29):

# 09 调试助手使用

> 达妙科技调试助手软件使用说明

---

## 调试助手简介

达妙科技调试助手是专为达妙电机设计的上位机软件，用于：
- 电机参数配置
- 电机校准和标定
- 实时调试和监控
- 固件升级

---

## 硬件连接

### 连接方式

使用达妙科技 USB 转 CAN 调试工具，连接电脑和电机：

1. **串口连接**
   - 电机调试串口通过 GH1.25 连接线-3pin 连接 PC
   - 用于参数设置、校准、固件升级

2. **CAN 连接**
   - 电机电源接口中 CAN 通信端子通过 XT30(2+2)-F 插头连接线连接 USB 转 CAN 调试工具
   - 用于实时控制和调试

3. **电源连接**
   - 连接电源接口，为电机供电

### 连接步骤

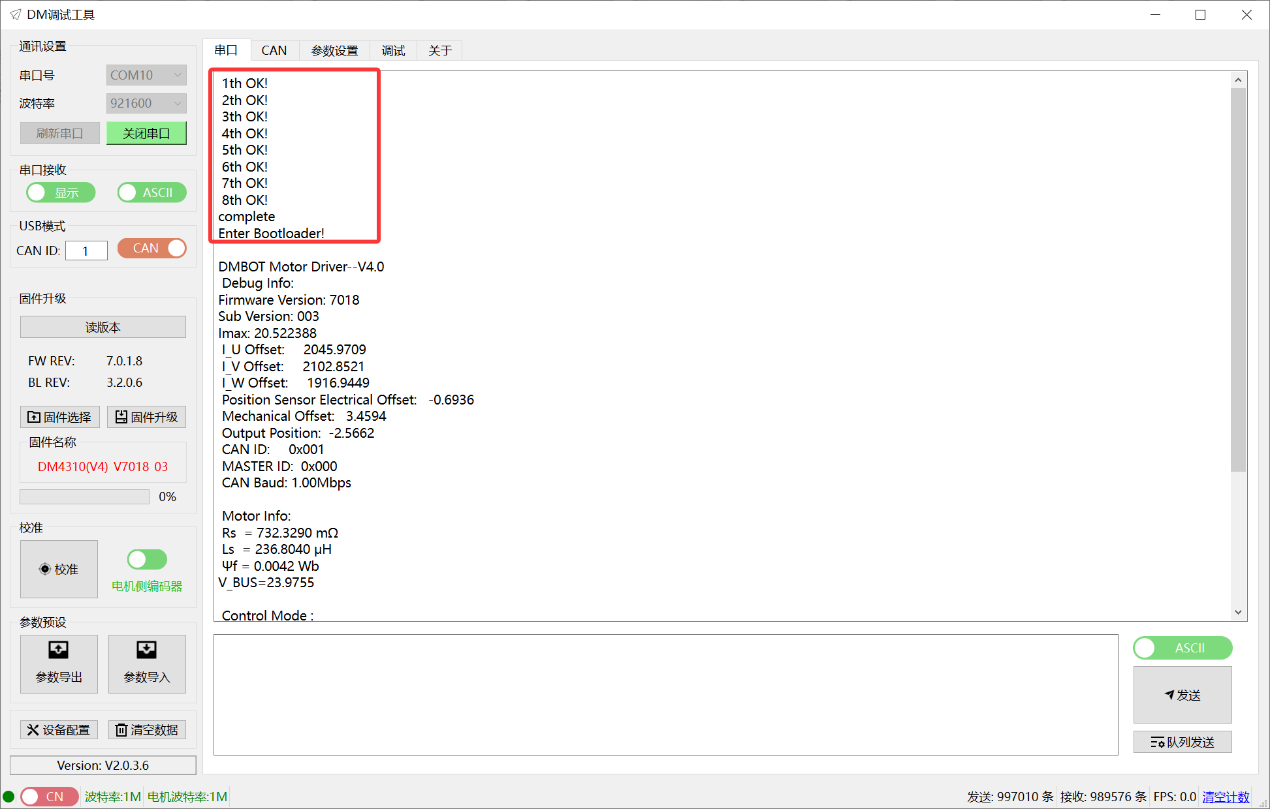
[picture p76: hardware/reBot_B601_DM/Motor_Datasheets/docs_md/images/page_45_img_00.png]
调试助手连接界面


1. 连接电机的串口、CAN 口以及电源接口
2. 电脑端打开达妙科技调试助手
3. 选择相应的串口设备并打开串口
4. 给电机供电
5. 串口会打印信息，**Control Mode** 指示当前驱动模式

---

## 软件界面

### 主要功能区

调试助手主要包含以下功能区：

1. **连接设置**
   - 串口选择
   - CAN 接口选择
   - 波特率设置

2. **参数设置**
   - 读取参数
   - 写入参数
   - 参数标定
   - 编码器校准

3. **调试界面**
   - MIT 模式调试
   - 位置速度模式调试
   - 速度模式调试
   - 力位混控模式调试

4. **固件升级**
   - 串口固件升级
   - CAN 固件升级
   - 版本查看

5. **监控显示**
   - 实时参数曲线
   - 温度监控
   - 状态显示

---

## 基本操作

### 1. 连接电机

#### 串口连接
1. 选择正确的串口号
2. 点击"打开串口"按钮
3. 观察串口打印信息，确认连接成功

#### CAN 连接
1. 选择 CAN 接口
2. 设置正确的波特率（默认 1 Mbps）
3. 确认 CAN ID 设置正确

### 2. 读取参数

1. 确保串口已连接
2. 点击"参数设置"标签卡
3. 点击"读参数"按钮
4. 等待参数上传完成
5. 核对参数是否正确

### 3. 修改参数

1. 先读取当前参数
2. 在界面上修改需要更改的参数
3. 确认修改无误
4. 点击"写参数"按钮
5. 等待写入完成
6. 电机会自动复位

> **注意**：写参数时请确保电机处于失能状态

### 4. 校准电机

#### 电机侧编码器校准
1. 点击"参数设置"标签卡
2. 确保电机空载且可自由转动
3. 点击"校准"按钮
4. 等待校准完成
5. 查看校准结果

#### 输出轴编码器校准
1. 点击校准按钮旁边的滑块
2. 切换至"输出轴编码器"状态
3. 点击"校准"按钮
4. 等待校准完成
5. 查看校准结果

### 5. 参数标定

1. 点击"参数设置"标签卡
2. 点击"参数标定"按钮
3. 电机会转动，保持空载状态
4. 等待标定完成
5. 查看标定结果

### 6. 调试电机

1. 确保 CAN 已连接
2. 选择对应的控制模式标签卡
3. 点击"使能"按钮
4. 设置控制参数
5. 勾选"定时发送"
6. 点击"更新"和"发送"按钮
7. 观察电机运行状态和参数曲线

### 7. 固件升级

#### 串口升级
1. 连接串口
2. 点击"固件选择"按钮
3. 选择固件文件
4. 确认固件名称正确
5. 点击"固件升级"按钮
6. 等待升级完成

#### CAN 升级
1. 连接 CAN
2. 将 UART 切换成 CAN
3. 填入要升级的电机 ID
4. 点击"固件选择"按钮
5. 选择固件文件
6. 点击"固件升级"按钮
7. 等待升级完成

---

## 详细使用说明

### 官方文档

详细调试过程请参考：**调试助手使用说明书（达妙驱动控制协议）V1.4.pdf**

### 下载链接

```
https://gitee.com/kit-miao/damiao-document/blob/master/
调试助手使用说明书（达妙驱动控制协议）V1.4.pdf
```

或访问达妙科技官网获取最新版本文档。

---

## 常见问题

### 1. 无法连接串口
- 检查串口线是否连接正常
- 检查串口号是否选择正确
- 检查是否有其他程序占用串口
- 尝试重新插拔 USB 线

### 2. 无法连接 CAN
- 检查 CAN 线是否连接正常
- 检查波特率是否设置正确
- 检查 CAN ID 是否正确
- 检查 CAN 终端电阻是否连接

### 3. 参数读取失败
- 确认串口连接正常
- 确认电机已上电
- 重新打开串口
- 重启调试助手

### 4. 参数写入失败
- 确认电机处于失能状态
- 确认参数值在有效范围内
- 重新读取参数后再写入

### 5. 校准失败
- 确认电机空载且可自由转动
- 检查电机是否有异常震动
- 重新进行校准
- 如多次失败，联系售后

### 6. 固件升级失败
- 确认固件文件正确
- 确认连接稳定
- 升级过程中不要断电
- 重新尝试升级

---

## 软件更新

### 获取最新版本

1. 访问达妙科技官网
2. 进入下载中心
3. 下载最新版本调试助手
4. 安装并使用

### 版本兼容性

- 建议使用 **V2.0.0.0 及以上版本**
- 推荐版本：**V2.0.3.4**
- 不同版本可能功能有所差异

---

## 技术支持

如遇到调试助手使用问题，请：

1. 查阅官方文档
2. 访问达妙科技官网技术支持页面
3. 联系售后技术支持

---

**返回** [00_目录.md](00_目录.md)  
**上一章** [08_固件升级.md](08_固件升级.md)

---

**文档整理完成**  
**整理日期**：2026-04-27  
**原始文档**：DM-J4310-2EC V1.2 减速电机使用说明书 V1.2

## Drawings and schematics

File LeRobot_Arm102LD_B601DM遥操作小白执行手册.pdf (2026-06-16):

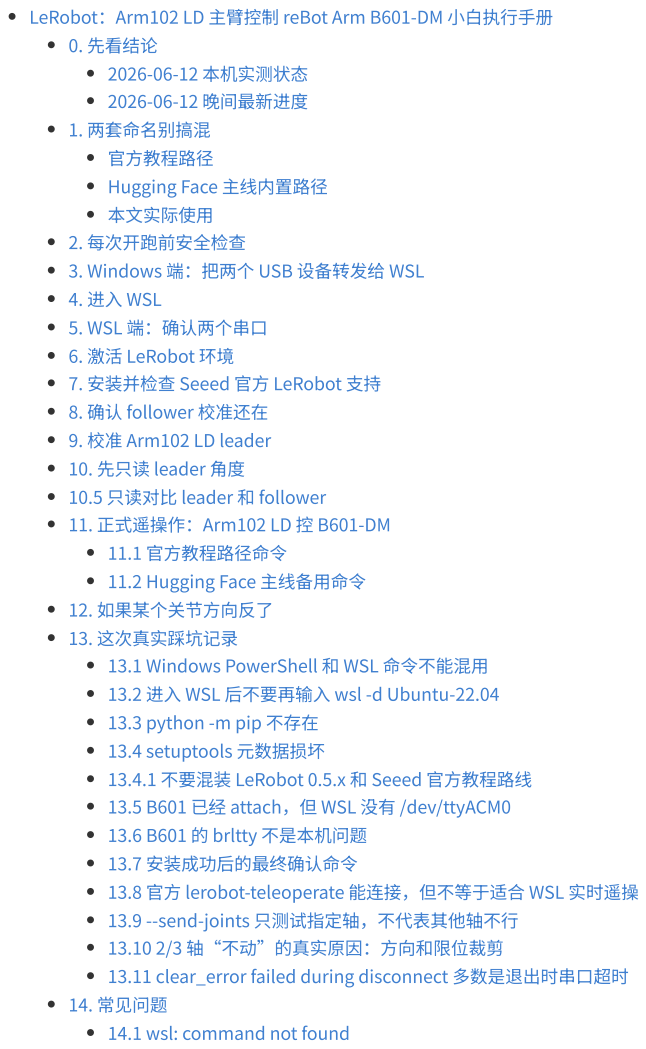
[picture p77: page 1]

LeRobot：Arm102 LD 主臂控制 reBot Arm B601-DM 小白执行手册
0. 先看结论
2026-06-12 本机实测状态
2026-06-12 晚间最新进度
1. 两套命名别搞混
官方教程路径
Hugging Face 主线内置路径
本文实际使用
2. 每次开跑前安全检查
3. Windows 端：把两个 USB 设备转发给 WSL
4. 进入 WSL
5. WSL 端：确认两个串口
6. 激活 LeRobot 环境
7. 安装并检查 Seeed 官方 LeRobot 支持
8. 确认 follower 校准还在
9. 校准 Arm102 LD leader
10. 先只读 leader 角度
10.5 只读对比 leader 和 follower
11. 正式遥操作：Arm102 LD 控 B601-DM
11.1 官方教程路径命令
11.2 Hugging Face 主线备用命令
12. 如果某个关节方向反了
13. 这次真实踩坑记录
13.1 Windows PowerShell 和 WSL 命令不能混用
13.2 进入 WSL 后不要再输入 wsl -d Ubuntu-22.04
13.3 python -m pip 不存在
13.4 setuptools 元数据损坏
13.4.1 不要混装 LeRobot 0.5.x 和 Seeed 官方教程路线
13.5 B601 已经 attach，但 WSL 没有 /dev/ttyACM0
13.6 B601 的 brltty 不是本机问题
13.7 安装成功后的最终确认命令
13.8 官方 lerobot-teleoperate 能连接，但不等于适合 WSL 实时遥操
13.9 --send-joints 只测试指定轴，不代表其他轴不行
13.10 2/3 轴“不动”的真实原因：方向和限位裁剪
13.11 clear_error failed during disconnect 多数是退出时串口超时
14. 常见问题
14.1 wsl: command not found

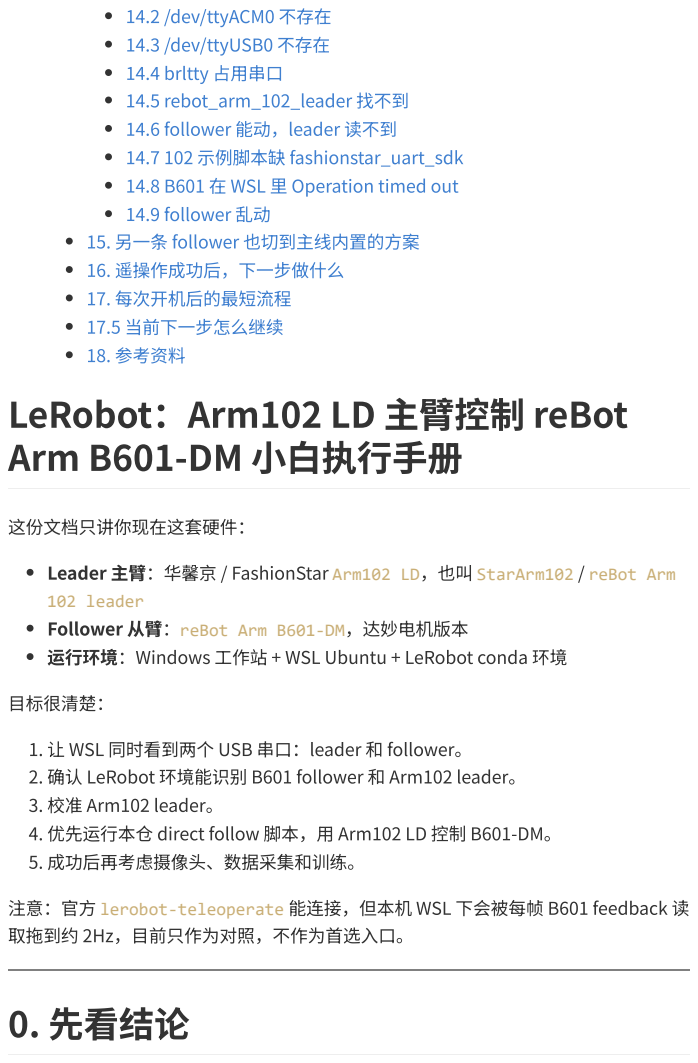
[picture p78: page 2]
这份文档只讲你现在这套硬件：; 目标很清楚：; 0. 先看结论

14.2 /dev/ttyACM0 不存在
14.3 /dev/ttyUSB0 不存在
14.4 brltty 占用串口
14.5 rebot_arm_102_leader 找不到
14.6 follower 能动，leader 读不到
14.7 102 示例脚本缺 fashionstar_uart_sdk
14.8 B601 在 WSL 里 Operation timed out
14.9 follower 乱动
15. 另一条 follower 也切到主线内置的方案
16. 遥操作成功后，下一步做什么
17. 每次开机后的最短流程
17.5 当前下一步怎么继续
18. 参考资料
LeRobot：Arm102 LD 主臂控制 reBot
Arm B601-DM 小白执行手册

Leader 主臂：华馨京 / FashionStar Arm102 LD，也叫 StarArm102 / reBot Arm
102 leader
Follower 从臂：reBot Arm B601-DM，达妙电机版本
运行环境：Windows 工作站 + WSL Ubuntu + LeRobot conda 环境

1. 让 WSL 同时看到两个 USB 串口：leader 和 follower。
2. 确认 LeRobot 环境能识别 B601 follower 和 Arm102 leader。
3. 校准 Arm102 leader。
4. 优先运行本仓 direct follow 脚本，用 Arm102 LD 控制 B601-DM。
5. 成功后再考虑摄像头、数据采集和训练。

注意：官方 lerobot-teleoperate 能连接，但本机 WSL 下会被每帧 B601 feedback 读
取拖到约 2Hz，目前只作为对照，不作为首选入口。

你之前已经完成：

### B601-DM Web UI 控制。 B601-DM 重力补偿。 B601-DM 重力补偿锁止。 LeRobot follower 基础验证。 B601-DM follower 校准文件已有：follower1。

现在新增的是：

### 接入 Arm102 LD 主臂。 校准 leader。 用 leader 遥操作 follower。

# 2026-06-12 本机实测状态

当前这台工作站已经切回 Seeed 官方教程路线。官方教程明确建议使用

### https://github.com/Seeed-Projects/lerobot.git，不要混用 Hugging Face 实时

主线仓库。

已经确认：

WSL 发行版：Ubuntu-22.04。 Miniforge 路径：~/miniforge3。 conda 环境：lerobot。 官方工作目录：~/rebot_lerobot。 lerobot：0.4.4，editable 指向 /home/pc/rebot_lerobot/lerobot。 lerobot_teleoperator_rebot_arm_102：1.0.0，editable 指向 /home/pc/rebot_lerobot/lerobot-teleoperator-rebot-arm-102。 lerobot_robot_seeed_b601：1.0.0，editable 指向 /home/pc/rebot_lerobot/lerobot-robot-seeed-b601。 motorbridge：0.4.5。 python -m pip check：No broken requirements found。 lerobot-calibrate 和 lerobot-teleoperate 都来自 /home/pc/miniforge3/envs/lerobot/bin/。

当前串口对应关系：

Windows COM11 / CH340 | -> WSL /dev/ttyUSB0 | -> Arm102 LD leader

Windows COM8 / 2e88:4603 | -> WSL /dev/ttyACM0 | -> B601-DM follower

### 注意：COM 号和 BUSID 会随 USB 口变化。2026-06-12 晚间换口后，B601 从 1-8 变成

### 1-7，但仍然是 Windows COM8；102 主臂是 1-6 / COM11。

校准文件已经确认存在：

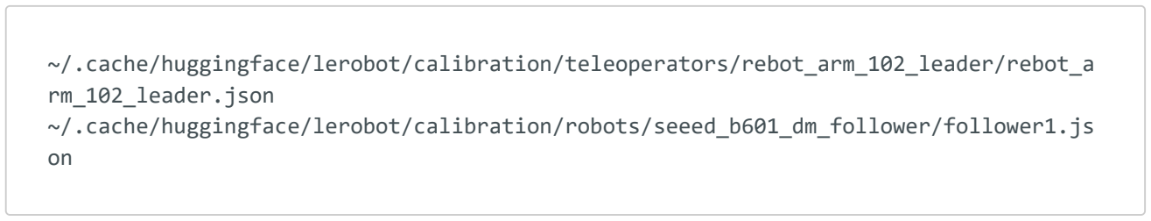
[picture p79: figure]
~/.cache/huggingface/lerobot/calibration/teleoperators/rebot_arm_102_leader/rebot_a rm_102_leader.json ~/.cache/huggingface/lerobot/calibration/robots/seeed_b601_dm_follower/follower1.js on

今天新增确认：

### Arm102 LD 之前读不了角度，是因为示例脚本缺 fashionstar-uart-sdk。 安装 fashionstar-uart-sdk==1.3.12 后，read_raw_angles.py 已经能正常连

续输出 102 主臂角度。

### B601 也能读到一次状态，但 WSL USB/IP 对 /dev/ttyACM0 写命令仍会

### Operation timed out。 当前 B601 的 shoulder_pan 读数约 90.00，而 102 主臂映射目标约 -0.30，两臂

初始姿态差约 90 度。这个状态下不能直接遥操作。

当前阶段结论：

### 1. Arm102 和 B601 零位已经重新校准并对齐。 2. B601 换 USB 口后，Windows COM8 原生读取稳定，WSL 慢速逐个读取稳定。 3. B601 在 WSL + LeRobot 下可以单独执行动作，说明 follower 的

send_action()、电机 ID、模式和基础通信是通的。

### 4. 官方 lerobot-teleoperate 能连接，但循环会反复读 B601 反馈，当前实测约 614ms / 2Hz，并出现 request_feedback failed: dm-serial write failed: Operation timed out。

5. 所以现在不要把“2、3 电机不跟”直接判断成电机问题。更准确的判断是：官方

### teleop 循环太慢/反馈读取超时，再叠加 102 主臂角度方向和 follower 限位裁剪，

导致部分轴看起来不跟。

# 2026-06-12 晚间最新进度

本轮实际操作：

### 102 主臂重新校准成功，生成 rebot_arm_102_leader.json。 B601 通过 WSL 官方 lerobot-calibrate 校准时在 disable_all 超时，未能直接

完成。

### B601 改用 Windows COM8 + motorbridge 原生通道执行 7 个电机

### set_zero_position()，7 个电机反馈约 -0.01°。 随后把 LeRobot 的 follower1.json 校准文件恢复到 ~/.cache/huggingface/lerobot/calibration/robots/seeed_b601_dm_foll ower/follower1.json。

### B601 换到新 USB 口后，BUSID 从 1-8 变成 1-7，WSL 需要重新 attach，必要时
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

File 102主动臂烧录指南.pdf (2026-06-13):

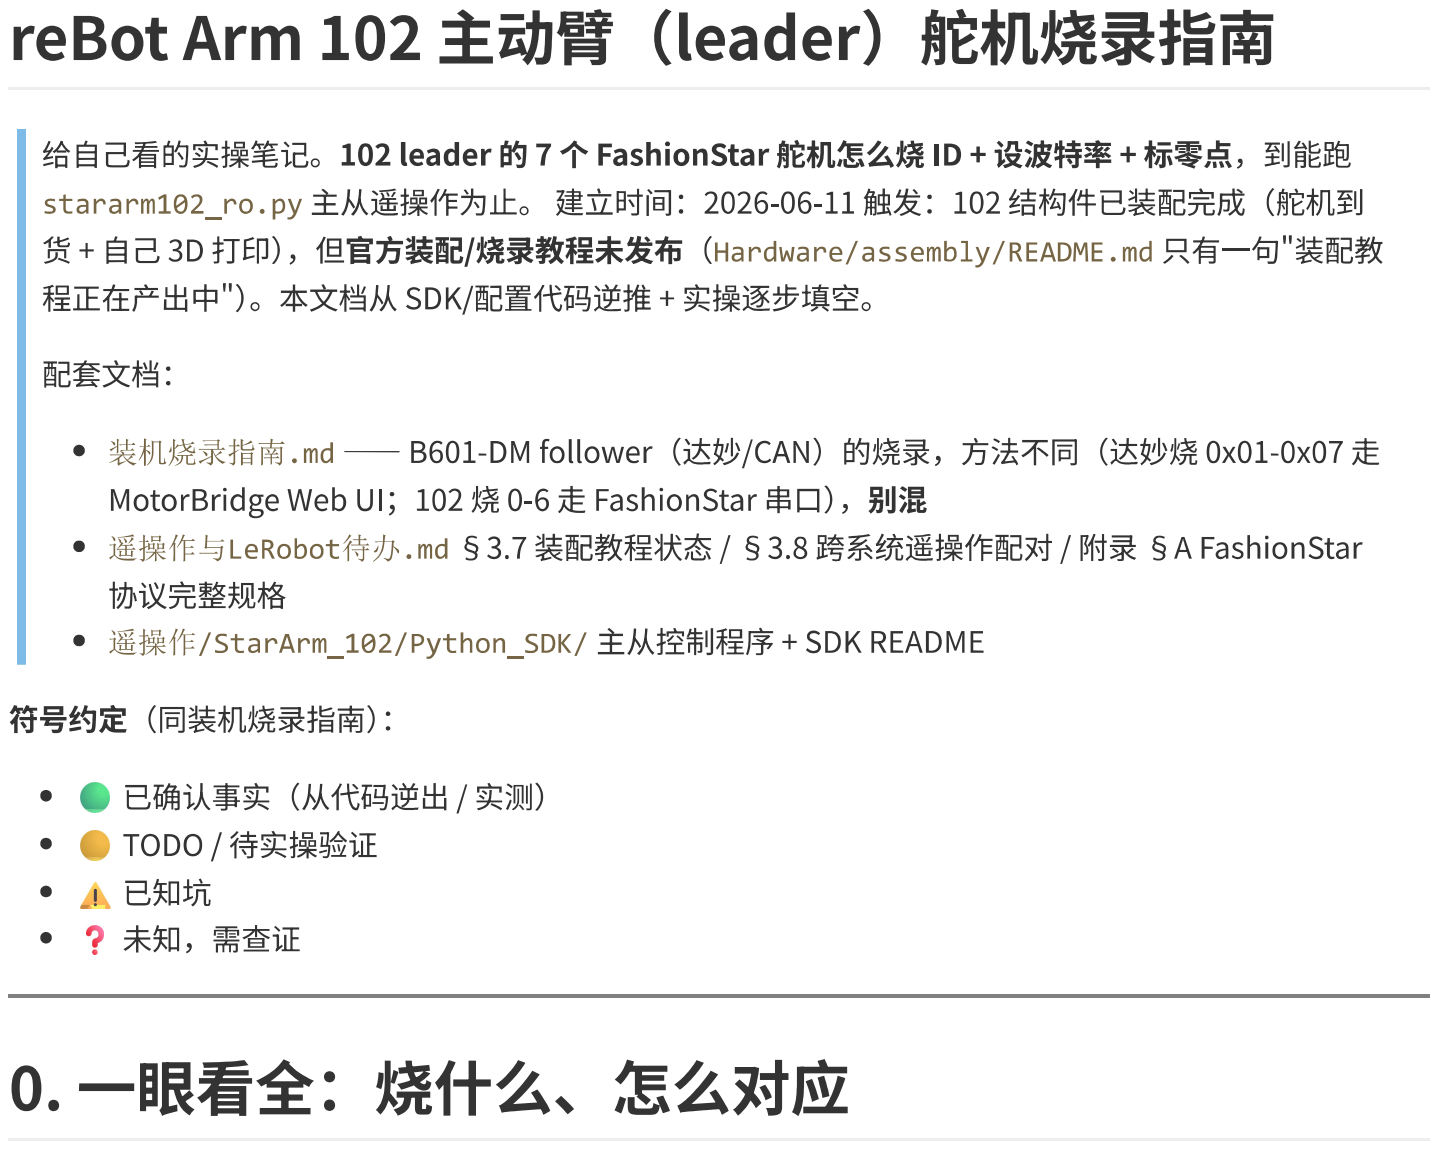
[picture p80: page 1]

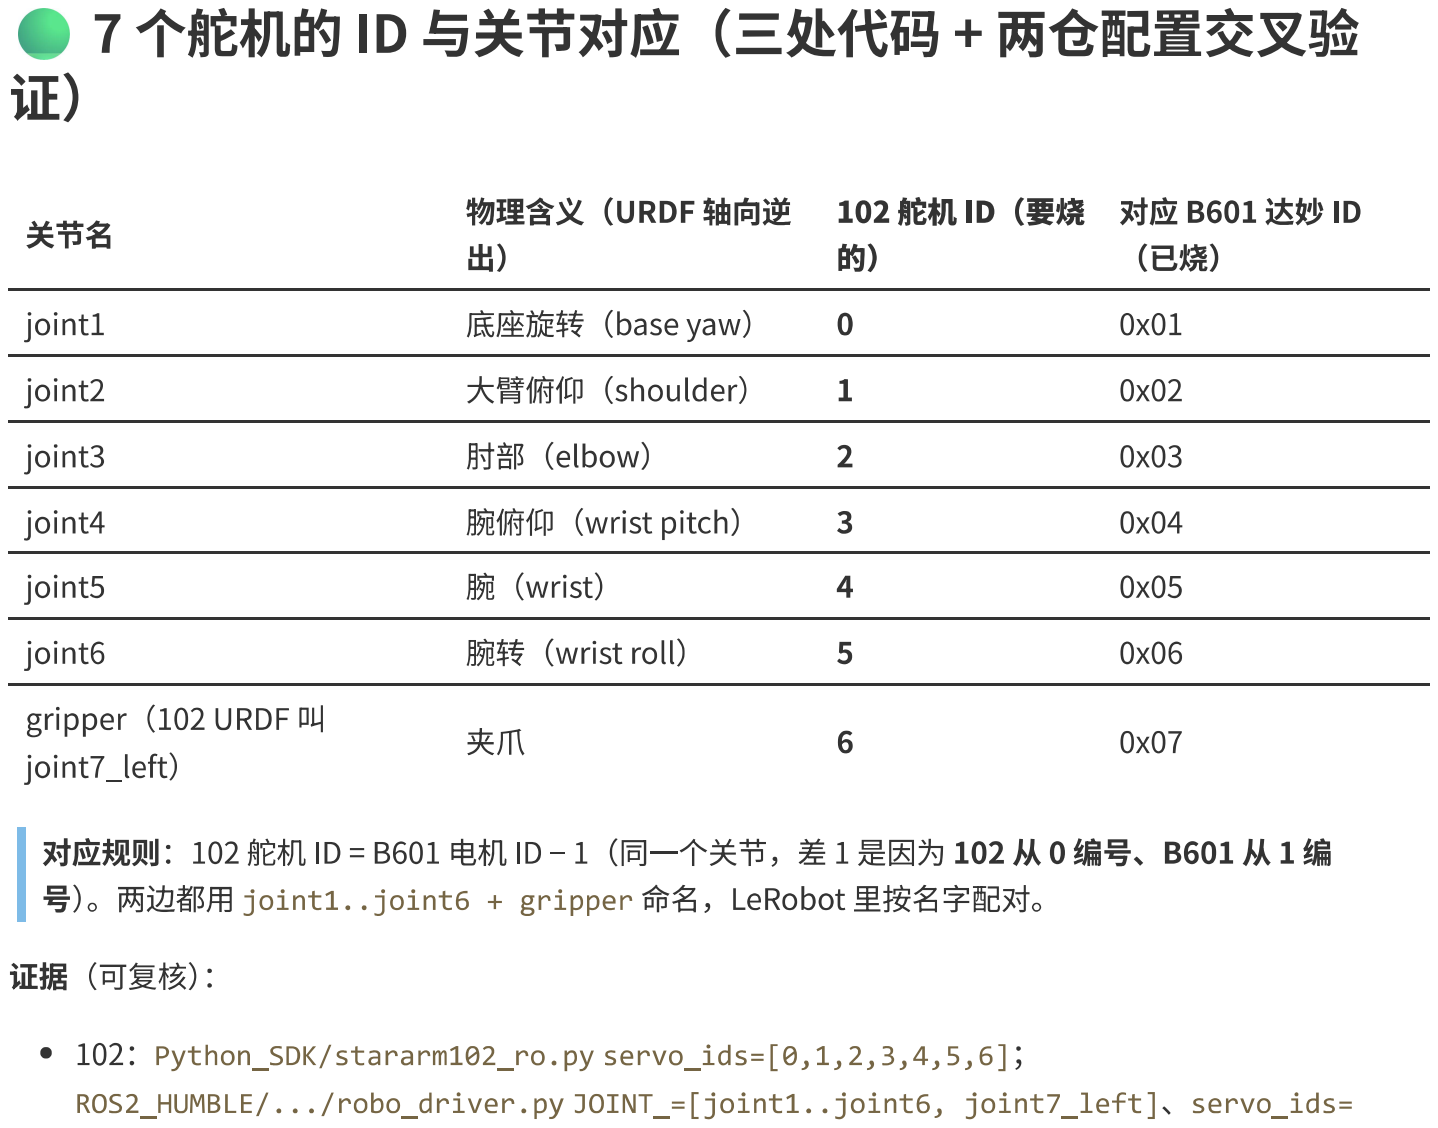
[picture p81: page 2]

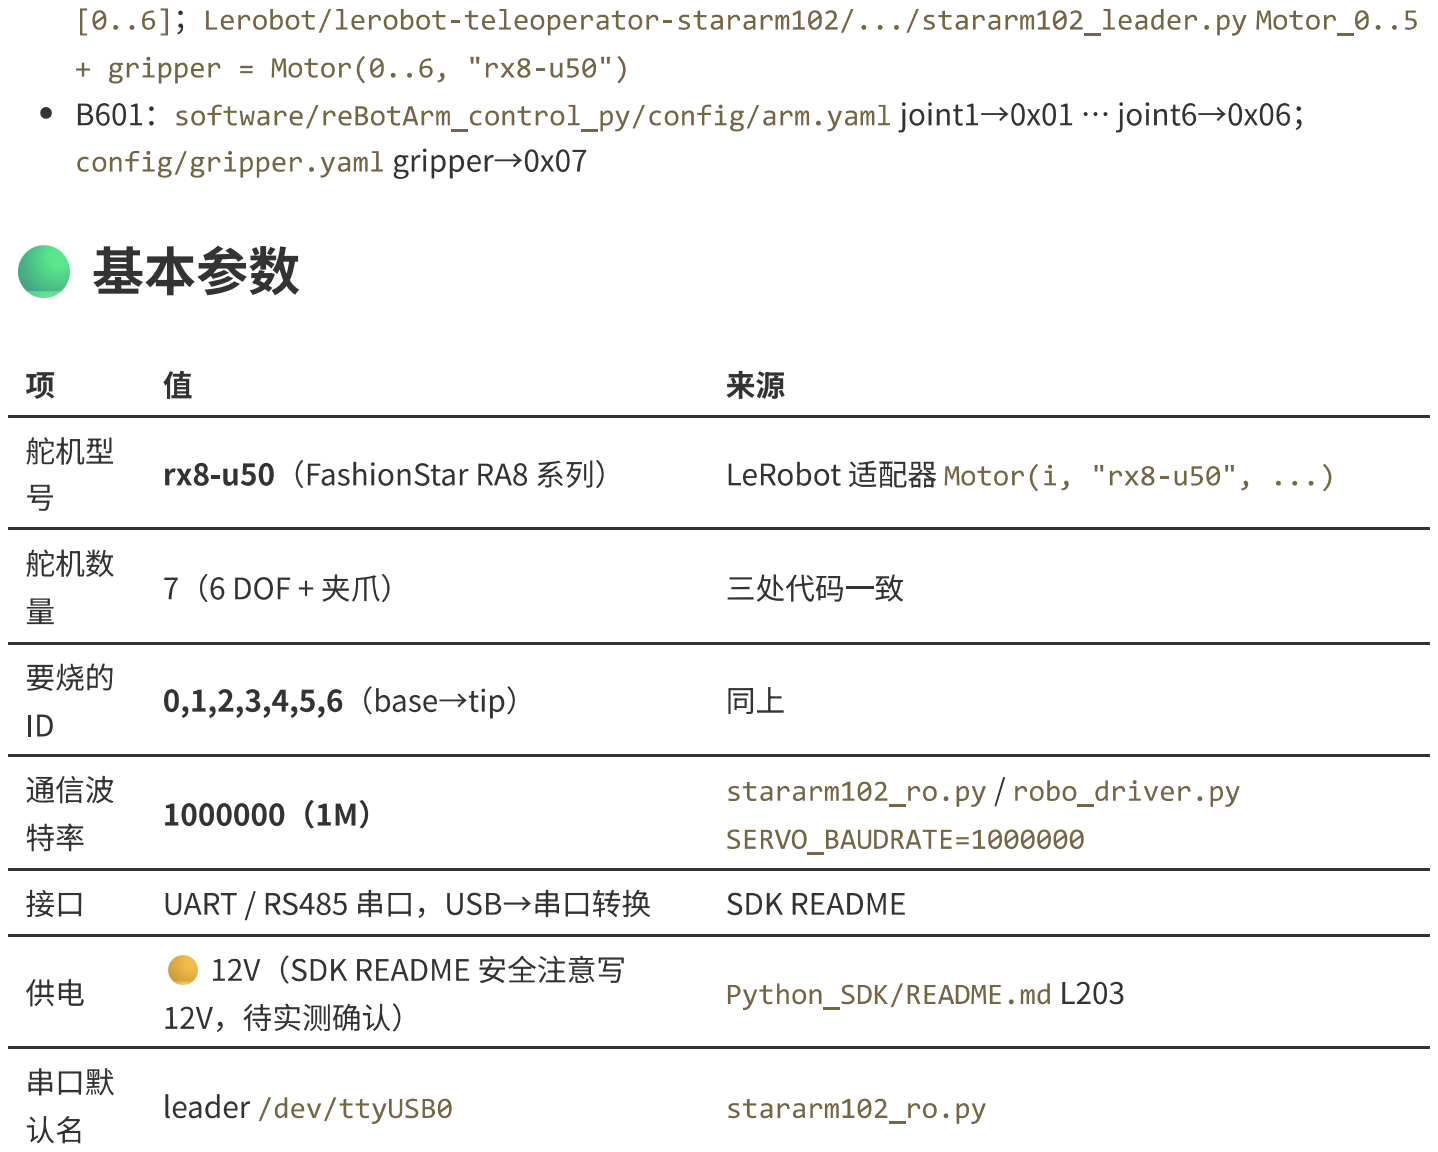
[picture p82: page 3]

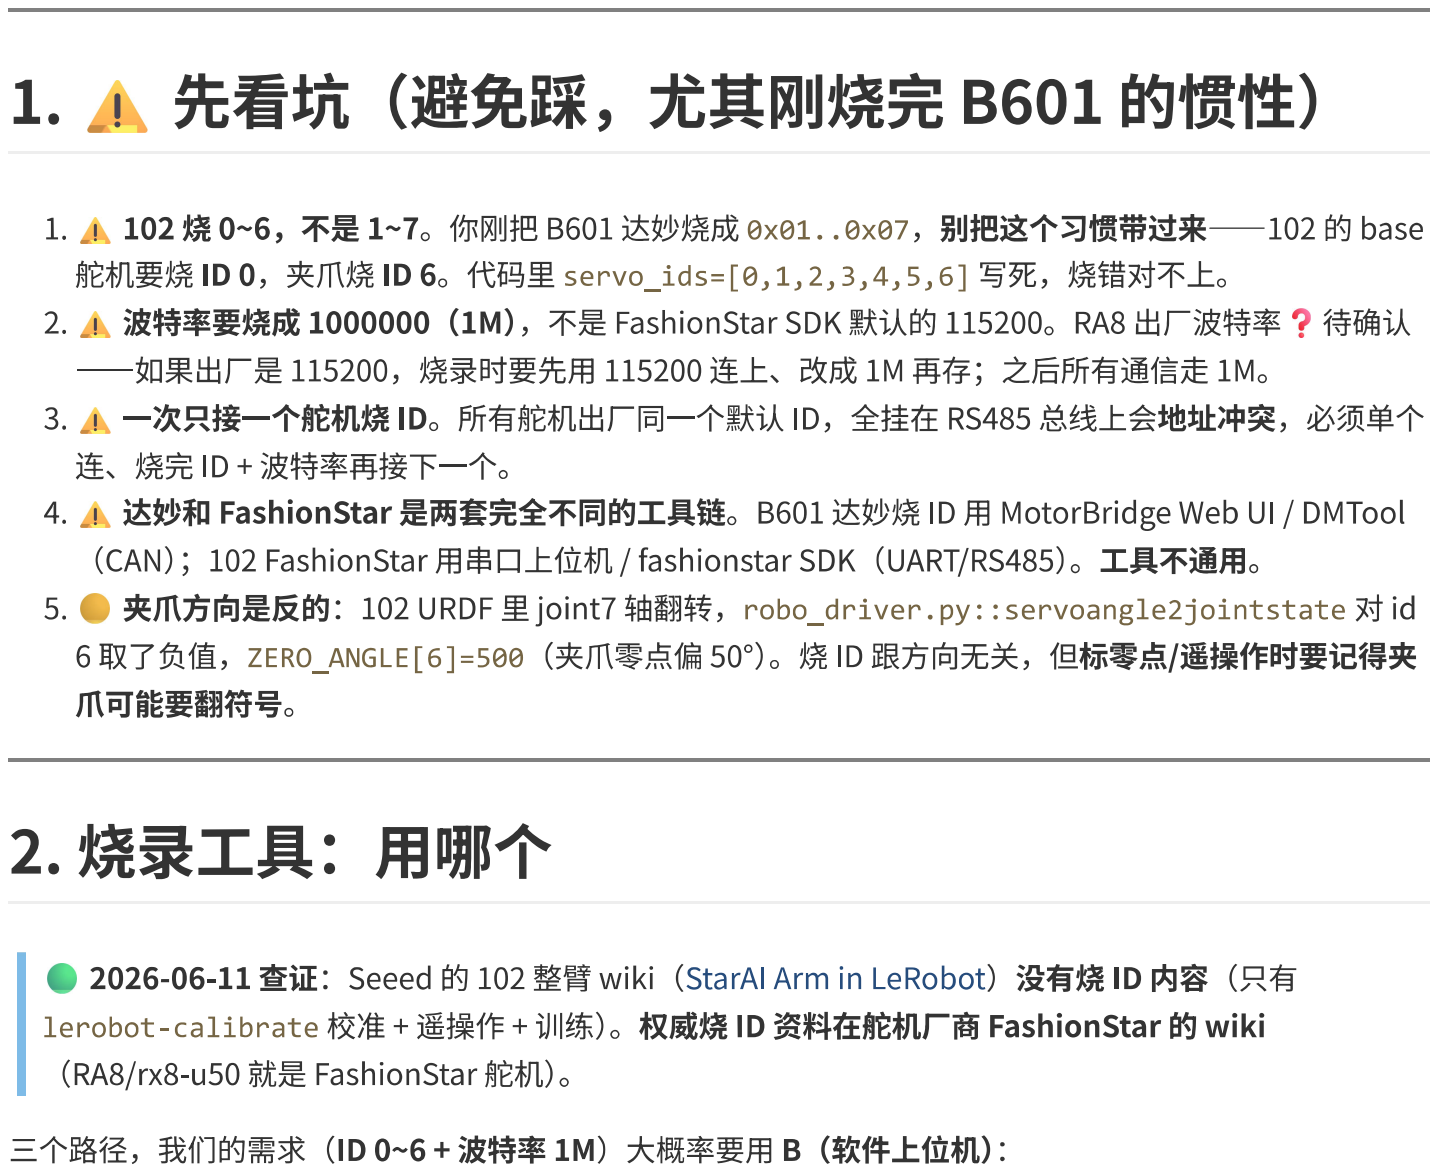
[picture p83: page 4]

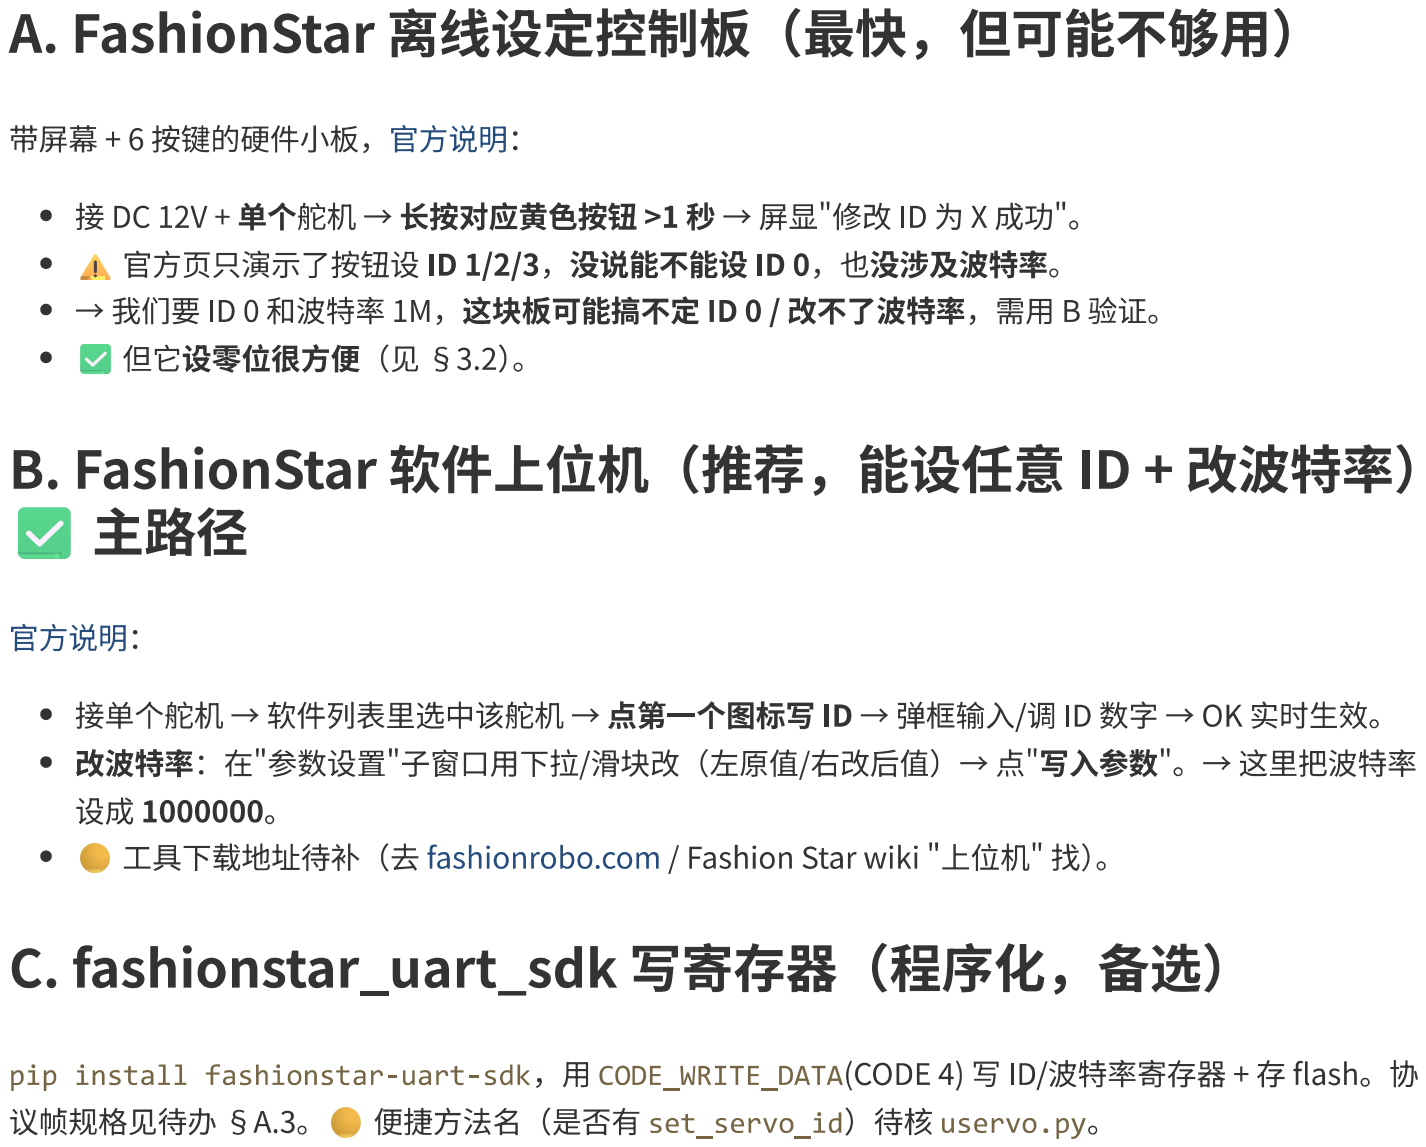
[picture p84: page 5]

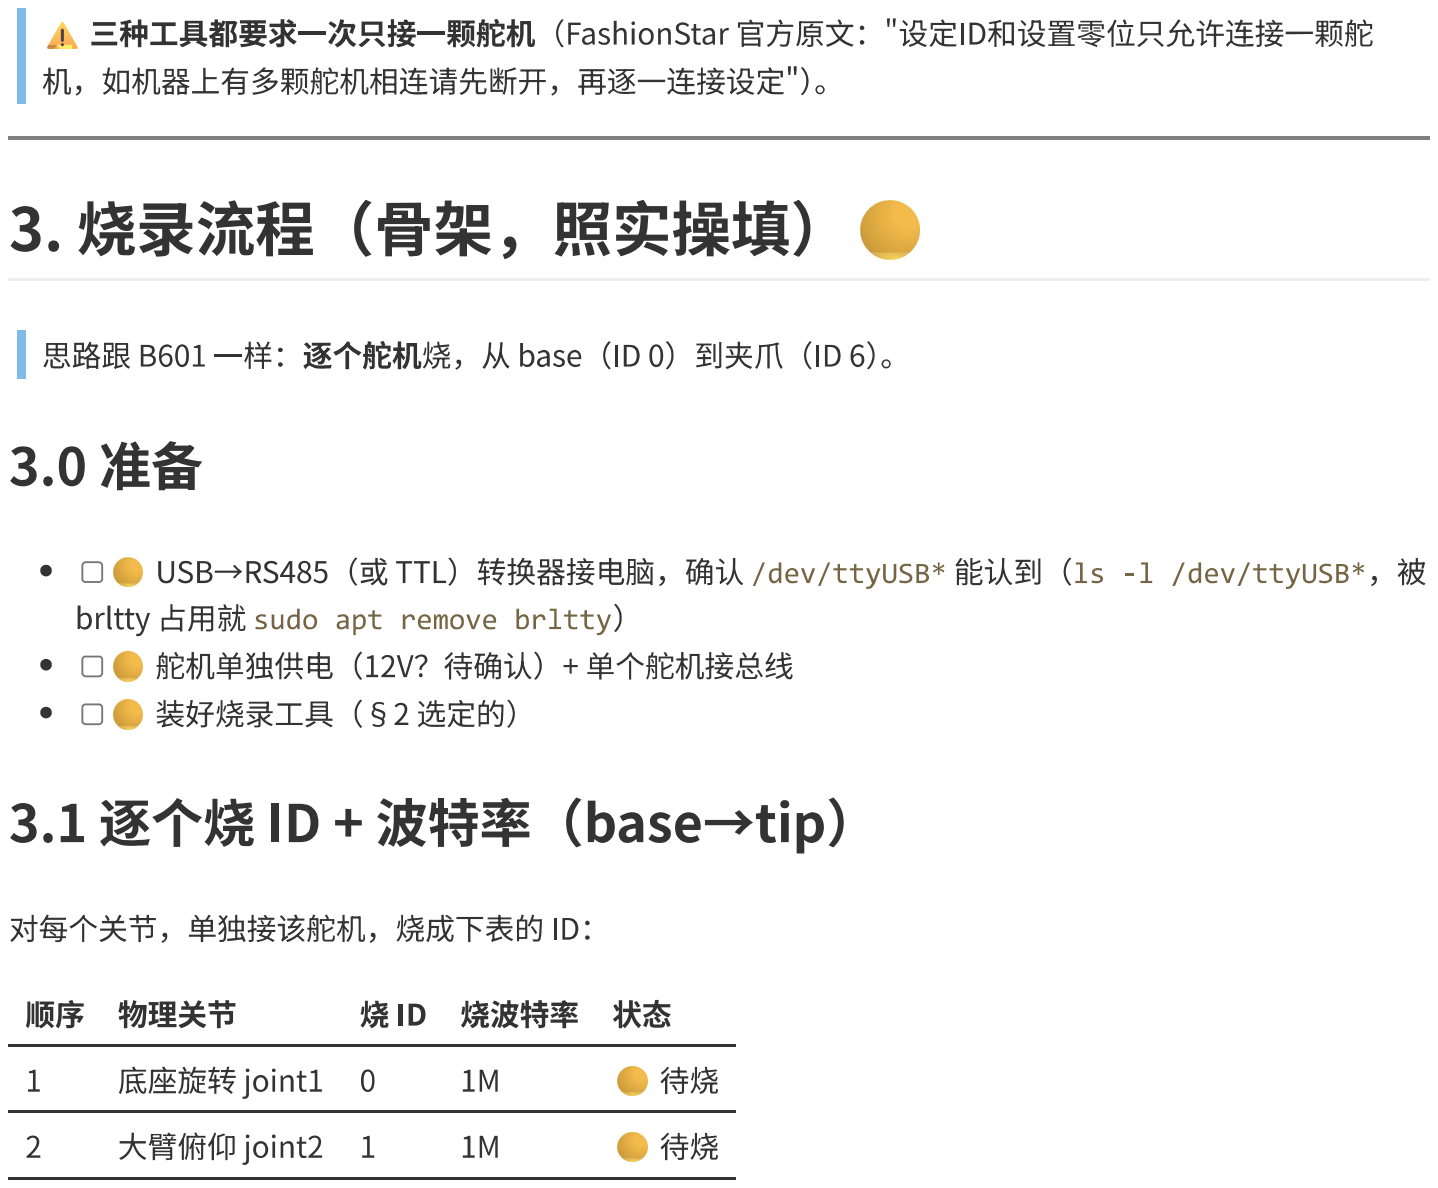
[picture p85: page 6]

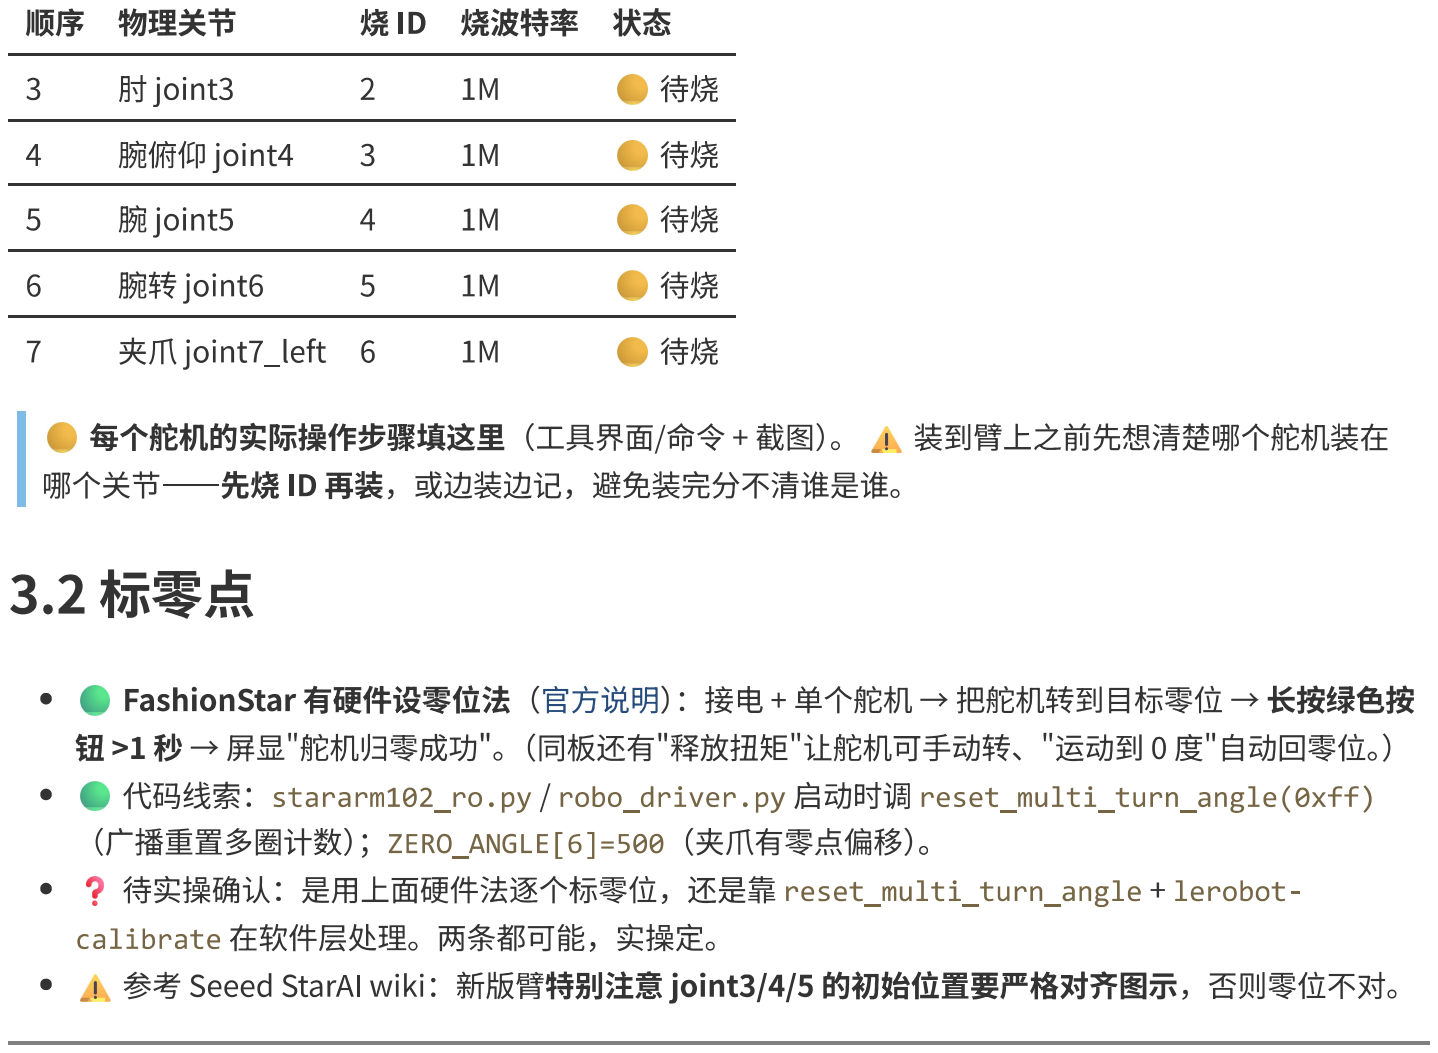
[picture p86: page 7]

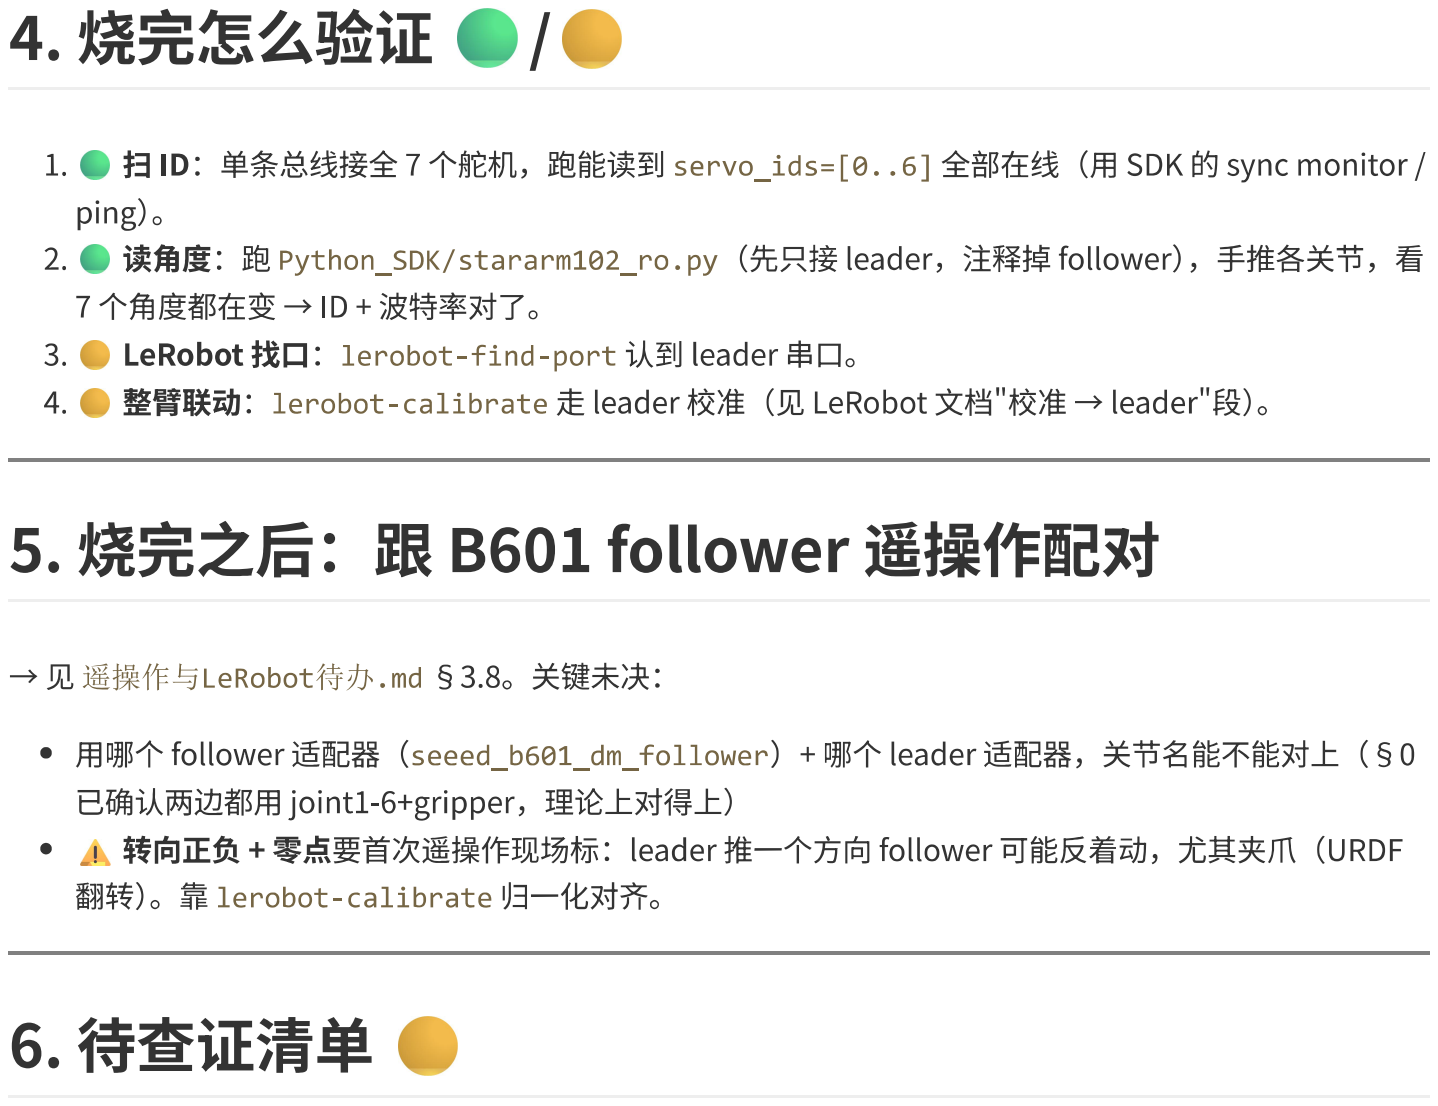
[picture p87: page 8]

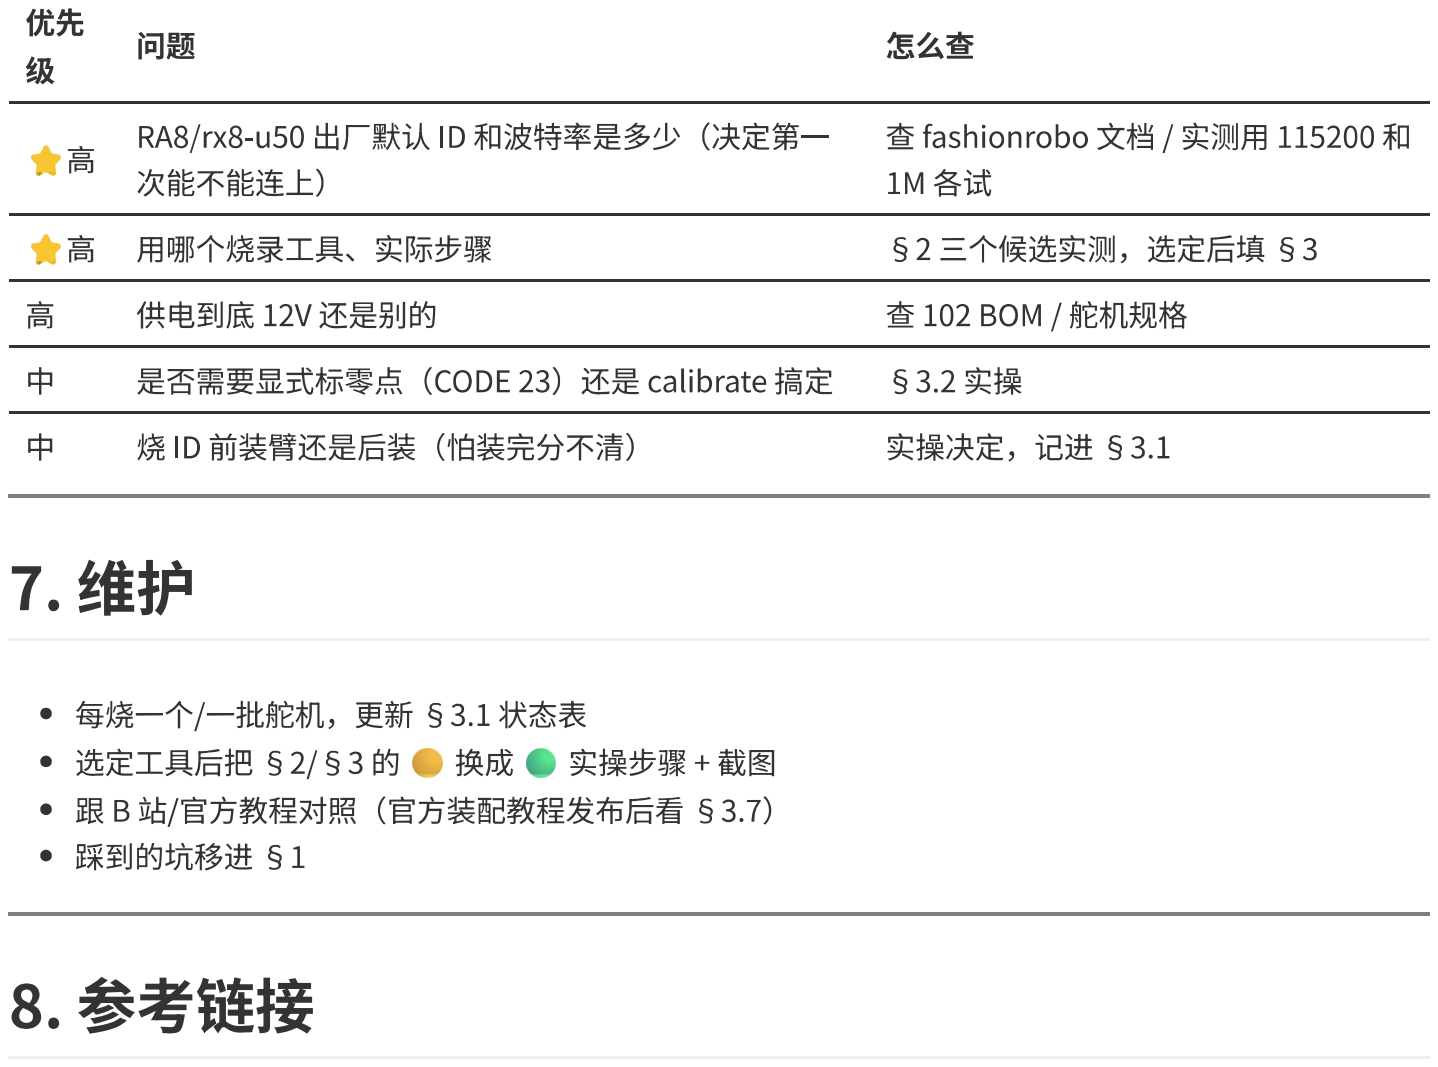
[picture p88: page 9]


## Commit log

2026-04-14 添加学习笔记和补充资料
    - 新增项目文档体系（PROJECT_NOTE/CHANGELOG/LEARNING_LOG/LEARNING_GUIDE）
    - 补充硬件资料（电机说明书、硬件总结、Motor Wiki）
    - 拉取软件仓库（MotorBridge + reBotArm_control_py）
    - 新增完整文档中心（docs/00_新手入门 ~ 03_MotorBridge）
    - 抓取并修复 8 个 wiki 教程页面
    - WSL2 环境搭建 + MeshCat 仿真验证
    本仓库 Fork 自 Seeed-Projects/reBot-DevArm
    标注 ★ 的内容为个人学习补充，非官方资料
2026-04-14 新增 Git 操作指南
    - 零基础友好的 Fork/Clone/Push/Pull 教程
    - 以本项目实际操作为案例
    - 包含常见问题排查和开源协议说明
    - 面向想学习开源项目但不懂 Git 的新手
2026-04-14 更新项目文档：记录 Git 指南和 GitHub Fork 操作
    - PROJECT_NOTE.md: 项目结构中添加 GIT_GUIDE.md，更新记录表添加 2026.04.14 Fork 操作
    - CHANGELOG.md: 新增第 5 节详细记录 Fork 到 GitHub 的完整过程和 Git 操作指南编写
2026-04-14 添加 .gitignore 文件
    - 忽略个人笔记文件夹（小红书进度/）
    - 忽略 Python 缓存和虚拟环境
    - 忽略 IDE 配置文件
    - 忽略系统临时文件
2026-04-17 同步上游 + 更新学习笔记（重力补偿）+ 忽略本地工具目录
    - 记录 2026-04-17 同步 Seeed-Projects/reBot-DevArm 的过程（CHANGELOG）
    - 新增 software/docs/02_reBotArm_control_py/重力补偿详解/ 学习笔记 4 篇
    - 更新 docs 入口 README 引用
    - .gitignore 新增 .baoyu-skills/、.obsidian/ 本地工具目录
2026-04-21 同步上游 2026-04-21：相机支架 STEP + 更新记录
    - 合并上游 2 个 commit（腕部相机支架 D435i/D405/Gemini2）
    - 新增 上游更新记录/2026-04-21_同步详情.md
    - 更新 CHANGELOG.md、PROJECT_NOTE.md
2026-04-21 新增遥操作系统目录 + 整理电机说明书版本
    - 新建 遥操作/ 文件夹：引入 Star Arm 102-LD 为 git submodule，编写主从臂配对说明和 LeRobot 工作流 README
    - 电机说明书：新增 J4310 V1.2 + J4340 V1.1 PDF，旧版归档到 Motor_Datasheets/旧版/，更新 README 参数表头版本号
    - 更新 PROJECT_NOTE.md 项目结构树，更新 CHANGELOG.md
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2026-04-21 重命名五个自建文档为中文文件名
    CHANGELOG.md → 操作日志.md
    PROJECT_NOTE.md → 项目总览.md
    LEARNING_LOG.md → 学习笔记.md
    LEARNING_GUIDE_01.md → 复现教程_01.md
    GIT_GUIDE.md → Git操作指南.md
    同步更新 software/docs/、上游更新记录/ 中的内部引用链接
2026-04-23 同步上游 2026-04-23：视觉抓取 Demo + 文档中文乱码修复
    上游变更（b837833..33f57b2，6 个 commit）：
    - 核心：新增「深度相机视觉抓取 Demo」状态行（YOLO + 深度相机）
    - D405 相机支架 STEP 小修订
    - 4 个翻译版 README 的 Pinocchio 链接换成 GitHub 仓库地址
    本地变更：
    - 新建 上游更新记录/2026-04-23_同步详情.md
    - 更新 上游更新记录/README.md 历史表
    - 更新 项目总览.md 官方更新进度表 + 最后同步日期
    - 操作日志.md 追加今日三条（重命名、gravity_lock_sim、同步上游）
    - 修复三处 UTF-8 乱码：项目总览.md / 操作日志.md / 上游更新记录/2026-04-21
    Co-Authored-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
2026-04-23 修复 Motor_Wiki / wiki_docs / software/docs 里的 UTF-8 乱码
    8 个 Markdown 共 10 处"���"字符修复：
    - 达妙/RobStride wiki 里的"开始/控制/使用/协议详情"
    - software/docs 里 MeshCat 仿真代码详解的"输入/返回/轨迹"等
    - Pinocchio MeshCat wiki 锚点链接里的 emoji
    乱码来源：之前 OpenCLI 抓页面时 UTF-8 编码未正确处理。
2026-04-23 补充复现教程 WSL2 USB 直通章节
    - 复现教程_01.md 第五步新增 5.0「WSL2 访问 USB 设备」
    - 5.1 硬件连接补充两条路径（达妙 USB2CAN vs 创芯 CANalyst-II）
    - 操作日志.md 记录今日第 4 条
2026-04-23 事后修正：2026-04-23 文档过度推断问题 + 新增 10 号算法学习笔记
    修正 5 处文档错误（用户指出）：
    1. gravity_*_sim.py 移到主仓库 software/sim_extras/（原在嵌套 repo 工作区）
    2. 项目总览.md：视觉抓取改回 🚧，注明中英文 README 冲突
    3. 上游更新记录/2026-04-23_同步详情.md：删除推断，只保留事实
    4. 复现教程_01.md：WSL USB 章节收紧表述，改用 lsusb 通用验证
    5. 操作日志.md：新增"事后修正"条目，诚实记录错误
    新增内容：
    - 学习笔记.md：10 号算法（末端速度锁止版重力补偿）2 页说明
    - software/sim_extras/：自建学习用仿真脚本目录 + README
    反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
2026-04-23 二次修正 2026-04-23 同步文档的 4 处口径问题
    1. 视觉抓取 Demo wiki 已上线（返回 200），改回 ✅
    2. 学习笔记.md 中 08 号算法编号错误（实际是轨迹控制）
    3. 积分项表述从"每秒"改为"每个控制周期"
    4. 操作日志中删除不存在文件的引用
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2026-04-23 复现教程 5.0 节加强新手友好：区分 Windows/WSL 命令 + 警告 BUSID 是示例
    本次踩坑：
    1. 用户在 WSL2 里跑 usbipd list，报 Command not found（usbipd 是 Windows 工具）
    2. 用户照抄文档里的 busid 2-3，报 There is no device with busid 2-3
    教程改进：
    - 5.0 顶部加醒目警告框，明确区分 Windows/WSL 命令的运行位置
    - 5.0.2 明确说明 BUSID 因机器而异，必须先 usbipd list 看自己的
    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
2026-04-27 记录 2026-04-26 上游同步：reBot v1.0 → v1.1 大改版
    新增 上游更新记录/2026-04-26_同步详情.md：
    - 官方 changelog 4 点（线束卡口、关节1电机修正、底座加强、线束卡扣）
    - 零件级变更（新增 / 重做 / 改名）
    - BOM 关键变化（齿轮内孔 5→8、螺丝体系细分、铜柱取消等）
    - 对学习项目的影响和推荐做法
    更新 操作日志.md：增加 2026-04-26 同步条目
    更新 项目总览.md：最后同步日期改 04.26，硬件 BOM 标注 v1.1
2026-04-29 整理达妙 DM-J4310 电机说明书为 Markdown + 调试经验记录
    - 新增 hardware/reBot_B601_DM/Motor_Datasheets/docs_md/：
    - 9 个 MD 章节（产品介绍/规格/硬件/工作模式/CAN通信/调试流程/调试操作/固件升级/调试助手）
    - images/ 80 张高清图片（PyMuPDF 提取，原始质量）
    - 新增 上游更新记录/2026-04-29_同步详情.md：
    - 主仓库无更新；MotorBridge/StarArm_102 有更新但暂不同步
    - .gitignore：排除 hardware/测试工具/（exe 33MB）和 hardware/测试数据/
    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
2026-04-29 确立"复刻基线维护原则"作为项目最高规则
    - 新增 复刻基线维护原则.md（主仓库根目录）：
    - 项目定位：复刻工程，不追最新
    - 4 个核心依赖都要 fork 到 fanhao375，submodule 只指 fork
    - 7 条核心规则：fork / 单源 / 检查 / 记录 / sync 分支 / commit 分层 / 不擅自 push
    - AI 协作红线：不擅自 push、不擅自升级 submodule、不擅自改 .gitmodules
    - 文档优先级：仓库文档为主，AI 记忆为辅
    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
2026-04-29 修正核心定位：从"不追最新"改为"追最新但 main 只接受验证过的最新"
    原表述"5 年后 clone 还能跑，不追最新"会误解成保守不动。
    实际目标是有节奏地追最新加上质量门控，引入"复刻基线"三层结构：
    - sync 分支：追最新、试升级（可丢弃）
    - main：已验证的"最新集成状态"（滚动更新）
    - baseline tag：阶段性可复现快照（永不变动）
    修改：
    - 复刻基线维护原则.md：项目定位改为"复刻集成工程"，新增三层结构图
    - 项目总览.md：AI 接手提示里的核心定位同步修正
    - 操作日志.md：补记本次定位修正的过程和原因
    不改变方向，只是把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
2026-04-29 更新 MotorBridge 上游地址（已迁移到 motorbridge 组织）
    发现项目已从个人账号 tianrking/MotorBridge 迁移到组织账号
    motorbridge/motorbridge，并拆分出独立子项目 motorbridge-studio。
    两个 URL 当前 HEAD 是同一个 commit（GitHub 自动重定向），
    但新组织地址才是官方位置，应该用新地址。
    - 复刻基线维护原则.md：第三部分仓库表格 + 三个相关位置改用新地址，
    补充历史背景说明
    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
2026-04-29 切换 MotorBridge/StarArm_102 submodule 到个人 fork
    完成阶段 B-2：把两个 submodule 从原作者仓库切换到个人 fork，
    让主仓库依赖永远只指向自己的 fork（符合复刻基线维护原则）。
    变更：
    - .gitmodules：
    - software/MotorBridge: tianrking/MotorBridge -> fanhao375/motorbridge
    - 遥操作/StarArm_102: servodevelop/Star-Arm-102 -> fanhao375/Star-Arm-102
    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
2026-04-29 更新阶段 B fork 切换记录
    补充操作日志中阶段 B 的完成状态：
    - MotorBridge 已 fork 到 fanhao375/motorbridge
    - Star-Arm-102 已 fork 到 fanhao375/Star-Arm-102
    - .gitmodules 已切换到个人 fork
    - 两个子模块已配置 origin/upstream
    - 两个子模块当前锁定 commit 已打本地 rebot-baseline-2026-04-29 tag
    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
2026-04-29 补充 Git 操作指南：复刻工程的进阶 Git 操作
    把今天做的复杂 git 操作沉淀进 Git 操作指南，新增 8 个进阶主题：
    1. 检查上游有没有更新（主仓库 + submodule）
    2. 把 submodule 切换到自己的 fork（修改 .gitmodules + sync + 内部 remote 配置）
    3. 打 baseline tag（阶段性可复现快照）
    4. submodule 升级走 sync 分支（不直接在 main 上做）
    5. 中文 commit message 用文件而非 HEREDOC（避免 Windows 下乱码）
    6. 撤销刚刚的 commit（reset --soft 而非 amend）
    7. commit 要分层（每类工作单独 commit，便于 bisect/revert）
    8. 保护 upstream 不被误推送
    新章节"进阶：复刻工程的 Gi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
2026-04-29 补全今日文档同步：操作日志 + 学习笔记 + 项目总览
    把今天最后一段工作（补充 Git 操作指南）和今天学到的新知识同步到对应文档：
    操作日志.md：
    - 修正 tag 名：rebot-baseline-2026-04-29 -> baseline-2026-04-29
    （实际打的 tag 按规则文档命名约定是 baseline- 前缀，无 rebot- 前缀）
    - 新增"7. 补充 Git 操作指南"条目，列出 8 个进阶主题
    学习笔记.md：新增"Git 进阶操作（今天踩坑学到的）"小节，6 个知识点：
    1. 中文 commit message 必须用文件，不能用 HEREDOC
    2. 撤销刚 commit 的：reset --soft 而不是 --amend
    3. submodule 切换到自己 fork 的完整流程
    4. bas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
2026-04-29 升级 MotorBridge submodule: f63896a → f7037b0 (v0.2.4)
    跟进 motorbridge/motorbridge 上游 50 个新提交。
    fork (fanhao375/motorbridge) 已与上游同步至 f7037b0。
    主要变化（按主题分类）：
    【架构重构】
    - 73c9949 Studio UI 拆分到独立仓库 motorbridge-studio
    （tools/factory_calib_ui_ws/ 大量文件被删除，迁到独立仓库）
    - ws_gateway 模块化：b2b67bf / 9e982ae / 9db93e2 / 6d90be3
    - factory-ui 模块化：2f72734 / ba36354
    【版本发布】
    0.1.8 → 0.1.9 → 0.2.0 → 0.2.1 → 0.2.2 → 0.2.3 → 0.2.4
    【与达妙电机相关的修复】
    - cc1117e factory-calib-ui-ws 同步最新达妙寄存器值（直接受益）
    - 99ecc65 RobStr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
2026-04-29 升级 StarArm_102 submodule: aaa80d7 → d777473
    跟进 servodevelop/Star-Arm-102 上游 4 个新提交。
    fork (fanhao375/Star-Arm-102) 已与上游同步至 d777473。
    主要变化：
    【模型与硬件】
    - 028d737 update: 更新新的模型（重要）
    - link7_left.STL: 151484 → 110284 bytes
    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
2026-04-29 记录 2026-04-29 submodule 升级详情
    新建 上游更新记录/2026-04-29_submodule升级.md：
    - 详细列出 MotorBridge 50 个 commit 的分类（架构重构 / 版本发布 /
    电机相关修复 / 新增功能 / 文档CI）
    - 详细列出 StarArm_102 4 个 commit + 模型文件大小变化 + 配置变化
    - 已完成动作 + 未完成验证 checklist
    - 回滚方法（git checkout baseline-2026-04-29）
    - 下次检查触发条件
    修订 上游更新记录/2026-04-29_同步详情.md：
    - 在文件顶部加"决策反转"提示，引用新文件
    - 保留原"暂不同步"决策的历史记录（不删，让决策过程可追溯）
    为什么保留两份记录：当天早些时候判断"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
2026-04-29 add soft finger step
    [Soft_Gripper_Finger.step, Soft_Gripper_Mount.step]
2026-05-05 升级 reBotArm_control_py submodule: a5078ae → 5ae4d56
    跟进 vectorBH6/reBotArm_control_py 上游 11 个新提交。
    通过 fanhao375 fork 的 develop 分支合并完成，已 push 到 fork。
    合并方式：
    - 共同祖先：a012a40 (fix gripper)
    - develop 独有：a5078ae (本地修复：清 .pyc + .gitignore)
    - upstream/main 多 11 个 commit：全是 README 更新和 PR merge
    - 无冲突 fast-merge，本地修复保留
    - 新增多语言 README：README_zh.md / README_es.md / README_JP.md / README_Fr.md
    （之前只有 README.md 英文，现在补齐 4 种语言）
    - 新增示例：example/1_damiao_text.py（达妙电机文本/示例代码）
    - README 多次更新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
2026-05-05 修正日期错误：今日同步实际是 2026-05-05 不是 2026-04-30
    之前同步上游时把日期记成了 2026-04-30，实际今天是 2026-05-05。
    本次只改文档内容和文件名，不改之前 commit 的历史（避免 force push）。
    修改内容：
    - 文件重命名：上游更新记录/2026-04-30_同步详情.md → 2026-05-05_同步详情.md
    - 文件内部：标题、同步时间字段全部更新
    - 操作日志.md：当日条目从 ## 2026-04-30 改为 ## 2026-05-05，链接同步更新
    - 项目总览.md：顶部"最后同步"日期 + 重大变更日志日期一并更新
    未改：
    - git commit 历史的实际时间戳（git 自动记录的真实系统时间，无需改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
2026-05-05 补充 2026-05-05 进度：motorbridge v0.2.4 补装 + 学习笔记
    把今天后续做的事和学到的新东西补到文档：
    操作日志.md（2026-05-05 条目下增加 2 节）：
    - 第 2 节：阅读 example/1_damiao_text.py（单电机 REPL 工具）
    - 第 3 节：补装 motorbridge Python 包 0.1.7 → 0.2.4
    含：之前给错的命令路径、正确路径在 bindings/python、
    验证步骤、新版 RID_/DAMIAO_ 常量、__version__ 属性消失的小坑
    学习笔记.md（新增 2026-05-05 段）：
    - MotorBridge v0.2.4 的 5 个关键认知：
    1. submodule 源码升级 ≠ Python 环境包升级（必须重 pip install）
    2. Python SDK 在 bindings/python/ 不在主目录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
2026-05-08 升级 reBotArm_control_py submodule 到 062bef9（同步 upstream 5537201 fix G）
    upstream `vectorBH6/reBotArm_control_py` develop 分支新增 1 个 commit：
    - 5537201 fix G
    - 新增 RobotArm.fresh() 空指令方法（actuator/arm.py）
    - example/9_gravity_compensation.py：mode_mit 后调用 fresh()
    - example/10_gravity_compensation_lock.py：_KP 8.0→7.0、_KD 1.0→0.8，并加 fresh()
    fork 内（fanhao375/reBotArm_control_py:develop）使用 merge 合入：
    - 5ae4d56..062bef9
    - 冲突解决：保持 fork 已有的 pyc 清理策略，actuator/__pycache__/arm.cpython-310.pyc 维持删除
    主仓 submodule 指针：5ae4d56 → 062bef9
    验证：
    - 静态验证 ✅（AST 语法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
2026-05-08 记录 2026-05-08 上游同步：reBotArm_control_py 升级到 062bef9
    vectorBH6/reBotArm_control_py:develop 新增 1 个 commit `5537201 fix G`：
    - 新增 RobotArm.fresh() 空指令方法（清零控制量但不切换模式）
    - example/9_gravity_compensation.py：mode_mit() 后调用 fresh()
    - 上游噪声：误提交 __pycache__/arm.cpython-310.pyc（fork 已 .gitignore，合并保持删除）
    按复刻基线维护原则规则 5 走 sync 分支：
    - fork 同步：5ae4d56..062bef9 已合入 fanhao375/reBotArm_control_py:develop 并 push
    - 主仓 submodule 指针 5ae4d56 → 062bef9（已在前一 c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
2026-05-09 升级 MotorBridge submodule 到 b9f7065（v0.2.4 → v0.2.6）
    upstream `motorbridge/motorbridge:main` 新增 3 个 commit，跨 v0.2.5 + v0.2.6 两个版本：
    - 21c12d7 Release Python package 0.2.5
    - a258ec5 fix(robstride): align scan and id handling for 0.2.6
    - b9f7065 docs: add CAN troubleshooting link to release note
    - ⭐ RobStride 电机底层修正（`motor_vendors/robstride/src/motor.rs` 大改，CLI 跟随更新）
    - Python 绑定新增 `robstride_ping_host_id` / `robstride_get_param_f32_host_id` 方法（带 host_id 参数）
    - `add_robstride_motor` / `robstride_set_device_id` 新增 ID 范围校验（motor_id 1..255、feedback_id/host_id 0..255）
    - 新增寄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
2026-05-09 记录 2026-05-09 上游同步：MotorBridge 升级到 b9f7065（v0.2.4 → v0.2.6）
    motorbridge/motorbridge:main 新增 3 个 commit：
    - 21c12d7 Release Python package 0.2.5（RobStride CLI 增强 + 文档更新）
    - RobStride 电机底层重写（扫描/ID 处理对齐）
    - Python 绑定新增 robstride_ping_host_id / robstride_get_param_f32_host_id 方法
    - add_robstride_motor / robstride_set_device_id 加 ID 范围校验
    - 删除 bindings/python/mintlify/ 文档目录（-17000+ 行）改放 docs/en docs/zh
    - 新增 release_test_notes/0.2.6.md 发版报告
    - b9f7065 docs: add CAN troubleshooting link to release not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
2026-05-12 fix Motor_Couver.step
    [01_Joint5_Cable Restraint_A.step, 01_Motor_Cover.step]
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2026-05-13 升级 MotorBridge submodule 到 a2b50ed（v0.2.6 → v0.2.8）
    上游 0.2.6 → 0.2.8 共 9 个 commit，全部 RobStride 电机相关
    （参数表补全、零点范围、运行时参数、文档注释、版本号 bump）。
    本工程使用达妙 DM 路径，motor_vendors/damiao 一行未改，
    bindings/python 仅 pyproject.toml + setup.py 版本号变更。
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2026-05-14 日期校准：5-13 第二批 → 5-14（实际同步日是 2026-05-14 周四）
    之前误信会话开始时系统时间显示的 2026-05-13，把当天工作记成"5-13 第二批"
    + 文件名 2026-05-13b + tag baseline-2026-05-13-2。系统时间 `date` 命令一查就知道
    实际是 2026-05-14。
    修正：
    - git mv 2026-05-13b_同步详情.md → 2026-05-14_同步详情.md（+ 文件内日期校准声明）
    - 操作日志 "2026-05-13（第二批，傍晚）" → "2026-05-14" + 校准声明
    - 项目总览 最后同步时间 5-13 第二批 → 5-14；记录表 5-13 行修正"两批"为"一批"
    并补充装机烧录指南 §0.1/3.2/4.2/8 填实内容（之前漏列在 5-13 行）；新增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
2026-05-14 遥操作与LeRobot待办：新建专门文档记录 leader 选型/比例调整等未知
    LeRobot 集成跟单臂装机不一样，复杂度高、维度多（leader 选型、几何匹配、
    框架成熟度、上游版本追踪），值得单独建文档跟踪。
    主要内容：
    - 当前硬件/软件状态清单 + 已确认事实（含 reBotArm_control_py 无多臂代码、
    follower 适配器代码已为 6 DOF leader 做兼容等关键发现）
    - Leader 选型决策矩阵（reBot Arm 102 配套 vs SO-ARM101 替代）
    - 5 个未解技术问题清单（已查清"手调比例"实际是 joint_limits 等 3 类参数）
    - 6 阶段路线图（装机 → 单臂验证 → LeRobot follower → leader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
2026-05-18 同步 submodule：MotorBridge bcfc3c1 (v0.3.2) + reBotArmController_ROS2 682d12f
    MotorBridge 681f021 → bcfc3c1（9 commit）：
    - release v0.2.9 + v0.3.0 + v0.3.1 + v0.3.2
    - RobStride 协议大改（protocol.rs +93 行）+ fault report fix + mode hardening
    - Python CLI timing fix
    - LICENSE 更新
    - 脚本重命名：scripts/slcan_restart.sh → canable_restart.sh
    - 测试方案重命名：slcan endurance → socketcan endurance
    - 达妙路径基本零改动（controller.rs 仅 1 行 typo 级）
    - v0.3.x major bump 原因是 RobStride 协议规范化，对达妙用户无感
    reBotArmController_ROS2 92ceb76 → 682d12f（4 commit，+853/-241 行）：
    - 62d1e18: 重命名 driver_only.launch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
2026-05-21 同步 MotorBridge submodule bcfc3c1 → 96dddf3 (v0.3.2 → v0.3.5)
    MotorBridge 8 commit：
    - f7037e6 chore: align package metadata + lint config
    - 9dec7c2 fix: stop controller polling on drop (Drop impl 自动清线程)
    - e36cefd ci: allow websocket handshake error size lint
    - bc24a7b release: prepare v0.3.5
    - 24c891a fix: expose robstride state sequence
    - 70d3f40 Revert "fix: expose robstride state sequence"
    - 503fb15 feat: stream robstride observation parameters
    - 96dddf3 feat: support damiao observation parameter stream（ws_gateway 层）
    ⭐ 注意：96dddf3 虽然 commit message 说 "damiao observation parameter stream"，
    实际是 integrations/ws_gateway/ 层加了 WebSocket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
2026-05-24 同步 MotorBridge submodule 96dddf3 → a6c14d7 (v0.3.5 → v0.3.7)
    2 个 squash-release commit：
    - 041e27d Release v0.3.6
    Fixed: Windows PCAN RobStride 多 controller 抢通道 / 扫描后误报
    "controller has no motor" / ws_gateway RobStride 跳 ID
    Added: Python scan 回归测试 (tests/test_scan.py)
    - a6c14d7 Release v0.3.7
    Added: MOTORBRIDGE_WS_DEBUG / capabilities op / batch_scan op /
    scan_progress 流式事件 / PCAN 错误码 INITIALIZE/ILLHW 名称
    Fixed: RobStride 单 host 扫描实时打印 / ws_gateway request-level
    channel+model / Windows PCAN 时序 clamp
    达妙路径：✅ 零改动（motor_vendors/damiao + motor_abi + Python core.py 全未动）
    API 兼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
2026-05-28 同步 MotorBridge submodule a6c14d7 → 23c2299 (v0.3.7 → v0.3.9)
    - bb34133 Release v0.3.8
    - 23c2299 Release v0.3.9
    全是 RobStride / Windows PCAN / ws_gateway 增强（subagent 5-27 复核确认）：
    - 新增 bindings/python/examples/robstride_posvel_timing_demo.py
    - release_test_notes/0.3.8.md / 0.3.9.md
    达妙路径：✅ 完全零改动（motor_vendors/damiao + motor_abi + Python core.py 全未动）
    API 兼容性：100%（Controller / Motor / Mode / send_mit / ensure_mode 等签名未变）
    跨仓影响：lerobot-robot-seeed-b601 调用的 motorbridge API 100% 兼容
    按 memory 规则 spawn subagent 复核（5-27 完成）确认零风险。
    Co-Aut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
2026-05-31 同步上游 DM 电源组装资料 + 摄像头支架 STEP 修正（squash，排除大图）
    同步上游 Seeed-Projects/reBot-DevArm af0bb58..6f7b33f（5 commit 内容，PR #33 by LAN-GER）：
    - af0bb58: 4 个 3D 打印件 STEP 重新导出 + 删除顶层冗余 UVC32_mount.step（规范副本保留在 3D_Printed_Parts/）
    - DM 电源组装资料：
    · 电源外壳 3D 打印件 STEP ×3（上盖/滑盖/底盖）
    · 电源外购件参考图 ×7（LRS-350-24 / IEC 插座 / 接地线 / XT60 等）
    · 3D 件渲染图 ×3
    · readme.md / readme_zh.md 新增电源 BOM 表 + 组装步骤章节
    本地化处理（区别于上游，关键）：
    - 采用 squash 单亲提交而非 merge ——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
    [01_BASE_Link.step, 01_Lower_Arm_Filler_M.step, 01_Upper_Arm_Fuller_M.step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]
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2026-06-07 同步上游主仓 2026-06-07：社区贡献表 + DM 电源外壳 STEP 修正（squash）
    同步 Seeed-Projects/reBot-DevArm 6f7b33f..5606170（11 commit 内容）：
    - README.md：新增 "Contributions from Developers" 社区贡献表（ROS2 monitor/park/gravity-comp）+ 社区反馈图行
    - community/ 新增 4 张社区图（约 3.7MB）
    - ⭐ DM-power-Top Cover.STEP + Sliding Cover.STEP：XT60E 母座位置内移，方便装螺母（0fd962e，打印电源外壳用此版）
    沿用 squash 单亲提交（上游历史永久含 94MB 实拍图 blob，不可普通 merge）。
    已 spawn subagent 复核：无删除文件 / 未碰本地 readme 注记 / 风险零~低。
    [DM-power-Top Cover-Sliding Cover.STEP, DM-power-Top Cover.STEP]
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2026-06-07 升级 reBotArmController_ROS2 到 c6a4e68（682d12f → c6a4e68，5 commit）
    - MoveIt2 Humble 兼容修复（demo/hardware launch + moveit_launch_common + package.xml + arm.yaml，解决 Humble vs Jazzy 不兼容）
    - RobotArm.fresh() 用法修正（过滤 gripper_ 关节，对应 motorbridge 新增 request_fresh_state）
    - 体量 10 文件 +77/-61 纯文本；本仓暂未跑 ROS2，零消费影响
    subagent 复核：风险零。
    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
2026-06-07 修正记录：LeRobot 环境查实在另一台电脑（非未定位）
2026-06-11 同步上游主仓 2026-06-11：reSpeaker 语音集成 + 社区贡献表 + 柔性夹爪 STEP + XT30 转接线（squash）
    上游 5606170..1cf0ec9（13 commit，squash 单亲法）：
    - README 新增 reSpeaker 语音集成行（✅ Completed）+ 社区贡献表重排（新增 gamepad IK 遥操作 / D405 eye-in-hand TF）
    - 柔性夹爪 Soft_Gripper_Finger.step + Soft_Gripper_Mount.step 优化重导出
    - 新增 XT30U 母头→XT60 公头外购件图 + 电源 BOM 购买链接
    - 本地化：readme.md/readme_zh.md 保留 powerstep 实拍图未上传 GitHub 注记（用 patch 三方合入，未覆盖）
    ⚠️ 沿用 squash 单亲法：上游历史含约 94MB 实拍图 blob，主仓永不可普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
    [Soft_Gripper_Finger.step, Soft_Gripper_Mount.step]
2026-06-11 升级 MotorBridge 到上游最新 53fe6dd（73443c7 → 53fe6dd，2 commit）
    PR#8（KillingJacky）：ws_gateway handle_damiao_state_many 轮询达妙状态
    改为先 get_motor 复用、取不到才 add_motor，避免重复注册撞 ID 失败。
    - 仅动 integrations/ws_gateway/src/router/handlers/connection.rs 1 文件
    - motor_vendors/damiao/ 达妙核心 + bindings/python 均零改动（已实测 diff 空）
    - 无版本号 bump（仍 v0.4.5 线，未打新 tag）→ Python wheel 不用升级，仅更新指针
    - subagent 独立复核：极低风险，对 Python 绑定调达妙 CAN 路径零影响
2026-06-11 升级 reBotArm_control_py 到 0163c08（develop cherry-pick 2 个 main bugfix）
    追 develop 策略不变。develop 本身无新上游提交，但 upstream/main 有 2 个
    真实 bugfix，subagent 实测 cherry-pick 零冲突，故摘到 fork develop：
    - 36d4346 fix(urdf): join3 → joint3 typo（与 ROS bringup/arm.yaml 命名对齐）
    - 0163c08 fix(kinematics): get_joint_limits 改按 idx_q 索引
    （修 joint1-5 限位取错 + joint6 IndexError）
    对当前实跑的重力补偿(example 9/10)/IK 实测无影响（get_joint_limits 本工程未调用、
    typo 不影响力矩数值），属预防性修复。坚决不切 main（main 曾删达妙示例）。
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2026-06-13 升级 MotorBridge 到上游最新 38b8a56（v0.4.5 → v0.4.6，4 commit）
    ⭐ spawn 独立 subagent 复核确认低风险纯增量：
    - `b4a839a` feat：达妙型号表新增 `4340_v20` 别名（display 名 `4340X`，pmax12.5/vmax20/tmax28）+ display_model_name/display_models 辅助函数。**纯新增一行 + 两个函数**，现有 DM4340P/4340/4310 参数与匹配逻辑逐字节未动；按 limits 反查无歧义（4340_v20 vmax=20 vs 4340P vmax=10，tol~0.01 远小于差值，不会误命中）。
    - `13c6414` fix(ws_gateway)：浏览器可在 WebSocket query 传 token（header 之外多一路）；本机 loopback 无 token 用法零影响，不碰达妙控制路径。
    - 版本 bump 0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
2026-06-16 StarArm_102 重新对齐上游 e8b871f → e61f34e（上游重写历史）
    ⭐ spawn subagent 复核 + 独立核实：上游作者(jhl)把我们刚同步的 e8b871f(力控/角度/控制模式/按键 4 commit)
    重写压缩成更干净的单 commit e61f34e（共同祖先 d777473，已分叉非 ff）。fork 走 reset --hard + force-push 重新镜像。
    - ⭐ 新增官方 LeRobot 适配器包 Lerobot/lerobot-stararm102/（HD=leader teleoperator / FL=follower robot
    + read_button/read_leader/replay 示例 + 官方标定 joint 方向/范围值）——对标 102 leader 适配器有参考价值
    （但 follower 是 102 同构，非 B601 达妙异构，不能直接替代用户 direct_follow）。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
2026-06-16 记录 2026-06-13 第三次检查：StarArm_102 re-mirror e61f34e + control_py main 评估不同步
    - StarArm_102 上游重写历史 e8b871f→e61f34e，fork reset+force-push re-mirror（新增官方 lerobot 适配器包+清垃圾）
    - control_py main 8 commit 评估为破坏性重构，不同步，维持追 develop
    - 详情/总览/操作日志同步更新
2026-06-16 记录 2026-06-13 本地遥操作进展：Arm102→B601 全轴 direct follow 确认 + 一键启动脚本
    - 重新上电后全轴 direct follow（--fps 5 --invert-raw-joints shoulder_lift,elbow_flex）效果确认很好
    - 新增 tools/lerobot_debug/start_direct_follow_wsl.ps1 一键启动脚本
    - 更新 操作日志/项目总览/待办/执行手册
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2026-06-18 升级 MotorBridge submodule 到 v0.4.7
    38b8a56 (v0.4.6) -> 2b7b350 (v0.4.7)，3 commit：
    - bbcca2d fix(damiao): 模式切换加固 + 参数持久化（写寄存器改等 0x55 write-ack 3 次重试 / ensure_control_mode 改共享超时预算 + 切换前后持位 / store_parameters 自动 disable）
    - dadfe8d fix(dm-serial): 串口超时预算 1ms -> 10ms（缓解 USB-CAN 写超时）
    - 2b7b350 release: prepare v0.4.7
    达妙路径 +600 行新单测；Python API 100% 兼容（api_surface.json 仅版本号变）。
    方向对症我们 Arm102->B601 遥操作的 dm-serial write timeout / clear_error timeout。
    注意行为变更：写寄存器现等 write-ack，若 DM4340P/4310 固件不回 0x55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
2026-06-18 升级 reBotArmController_ROS2 submodule 到 a61efe4
    c6a4e68 -> a61efe4，9 commit，主线为 B601-RS（RobStride 版）新增支持：
    - 3abc13d/730455a/b4411b8/4ad6ac8 RS 版 URDF + MoveIt2 集成 + 重力补偿 + 分体夹爪 pick_place demo
    - d943b8f fix: B601-DM mit 控制器重力补偿 kp/kd 修正（[120,120,120,18,18,18]->2.0 / [8,8,8,2,2,2]->1.5）
    - d610116/7d3190a command-lock 仲裁 + 抢占式 safe_home（节点终止后执行）
    - 删除 msg/JointVelCmd.msg、srv/SetMode.srv；config 整合为 rebotarm_hardware.yaml（型号分层 dm/rs）；launch 参数改名 arm_config+gripper_config -> hardware_config + model
    含 63MB RS 专用 STL（30 个 mesh，DM 实操零价值）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
2026-06-20 原生 Ubuntu 跑通遥操作 (Arm102 LD → B601-DM)，固化三处适配器补丁
    - 迁出 WSL：原生 Linux 串口直连，官方 lerobot-teleoperate 60Hz 全 7 轴
    跟手，彻底解决 WSL usbipd 卡 2Hz + request_feedback timeout
    - 新增 tools/lerobot_native_linux/：apply_patches.py (幂等)、三个 .patch、
    start_teleop.sh、README，重装后一键恢复 ~/rebot_lerobot 里的本地修复
    1) leader get_action 取反 2/3 轴
    2) leader joint_ranges 改对称，修过 90° 跳回 0 的解缠翻转 bug
    3) follower max_relative_target=12 限速安全网
    - 更新操作日志(2026-06-20)、项目总览、小白手册原生 Linux 横幅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
2026-06-21 同步上游主仓 2026-06-21（squash 单亲）：RS 版电源组装资料 + 多语言文档更新
    上游 reBot-DevArm `63a3cfb(我们 06-18 同步点)..0522186`，全部为 RobStride(RS)
    版内容 + 文档，DM 版功能代码零改动。按 05-31 既定永久约束用 squash 单亲并把
    超大装配实拍图 gitignore。
    新增/更新：
    - RS 电源外壳 STEP×3 + 3D 件预览图×3 + 外购件参考图×8（共 ~7.4MB，保留）
    - 多语言 README（顶层 + RS readme）：Pinocchio 适配 wiki 链接、B601-RS 的
    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
    [RS-power-Bottom Cover.stp, RS-power-Top Cover-Sliding Cover.stp, RS-power-Top Cover.stp]
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2026-06-24 同步上游主仓 2026-06-24（squash 单亲）：DM 供电件装配步骤更新 + 打印件 STEP→stp
    上游 Seeed `0522186..67d233c`（实质 commit `de86d01`）：
    - DM 供电 3D 打印件格式迁移：删 3 个 .STEP，新增 3 个 .stp（前壳/后壳/滑盖）
    - DM 打印件预览图 3 张更新（取上游版）
    - DM readme.md/readme_zh.md：上游修正装配步骤（图引用 jpg→png、螺丝规格改 304 不锈钢、链接指向 .stp）
    - RS README.md：修正 RS 电源章节螺丝 BOM 错误
    - 4 个 README 均取上游更新，并保留本 fork「powerstep 大图本地化」警告块（DM 措辞 STEP→STP）
    按 2026-05-31 永久约束（主仓不可普通 merge upstream）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
    [DM-power-Bottom Cover.STEP, DM-power-Bottom Cover.stp, DM-power-Top Cover-Sliding Cover.STEP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]
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2026-06-27 撤销 max_relative_target 限速补丁(遥操作延时修复)
    第3补丁每帧读7电机状态+钳制目标致从臂延时;过90跳回0根因已被补丁2(量程对称)
    在源头修掉,限速无必要。恢复上游默认 None,延时改善。apply_patches 剩2补丁。
2026-06-27 记录 2026-06-27 阶段5数据采集:相机就位+lerobot-record跑通+23条干净数据
    相机就位(Insta360俯视/Gemini腕部均MJPG,rerun预览调构图)。lerobot-record全链路
    打通,踩平6坑(warmup超时/双相机USB带宽抢占→Gemini强制MJPG/Insta360只支持720p/
    display_data拖慢→关掉+写盘子进程/batch_size>1的NoneType bug/⚠️video=false会剔除
    相机非存PNG)。固有限制:每条间20-80s编码冻结。成果:block_in_box 录28→删5空条→
    23条干净(10125帧双路视频),打包455MB待拷5060Ti训练机。流程固化采数据_lerobot_record.md。
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2026-06-30 采数据封装脚本 + 训练脚本审核修复 + web 子模块更新（阶段2）
    新增 tools/lerobot_native_linux/start_record.sh：env 驱动起 lerobot-record（B601-DM 从臂 +
    Arm102 leader 遥操，双相机），6 个踩坑写死在命令里；RECORD_MOCK=1 发假录制进度供无硬件联调。
    start_train.sh 审核修复：
    - M2 OUTPUT_DIR 默认带时间戳（lerobot-train 对非空 output_dir 拒跑，否则第二次起训必挂）；
    - 新增 RESUME=1 续训分支（--config_path 旧 checkpoint + --resume=true）。
    web_arm_ui 子模块同步：record.html、server.js /api/record|cameras、训练站 M1/M3/M4/M5 修复。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
2026-06-30 看数据质检脚本 v3.0 视频定位 + web 子模块更新（阶段3 审核修复）
    dataset_quality.py：除质检外，从 meta/episodes 读每条每路相机的视频定位
    （videos/<vid_key>/{chunk_index,file_index,from_timestamp,to_timestamp}），供前端按 v3.0
    拼接视频 + #t=from,to 截段播放（修 S1：v3.0 多 episode 拼一个 file-NNN.mp4，非一 ep 一文件）。
    每条 try 包裹防一条脏数据拖垮整份报告；只读需要的列省内存。
    web_arm_ui 子模块同步：server.js（S1 视频路径/S2 防崩 done 守卫/M1 HF_LEROBOT_HOME+--root/
    info.json 准确条数/后缀 Range）、data.html（Media Fragment 截段播放）。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
2026-06-30 web_arm_ui 子模块更新：TCP 拖拽修复 + 孪生 surface（第1件）
    cockpit TCP 拖拽 pointer-events 修复；顶栏「跟随真机」开关把数字孪生提到明面。
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2026-06-30 物理仿真第4件：审核+实跑修复（模型层已在 Windows 上 mujoco 验通）
    在开发机 pip install mujoco 实跑验证(ROS 那层仍需 Linux)，连同独立 subagent 静态复核，修掉：
    - [我实跑发现] urdf_to_mjcf 的 re.sub 替换串吃到 Windows 路径反斜杠报 bad escape \c → meshdir 转正斜杠 + 函数替换。
    - [实跑+审核M1] 相邻连杆全分辨率碰撞网格凸包自碰，把臂"焊死"(qfrc_actuator 27 被 qfrc_constraint -27 抵消，
    关节不动)。MVP 固定底座无抓取，<flag contact="disable"> 关接触；以后抓取再开+加 <contact><exclude>。
    - [审核S1] 强制 compiler autolimits=true：执行器只写 ctrlrange/forcerange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

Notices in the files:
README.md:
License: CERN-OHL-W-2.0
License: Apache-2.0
